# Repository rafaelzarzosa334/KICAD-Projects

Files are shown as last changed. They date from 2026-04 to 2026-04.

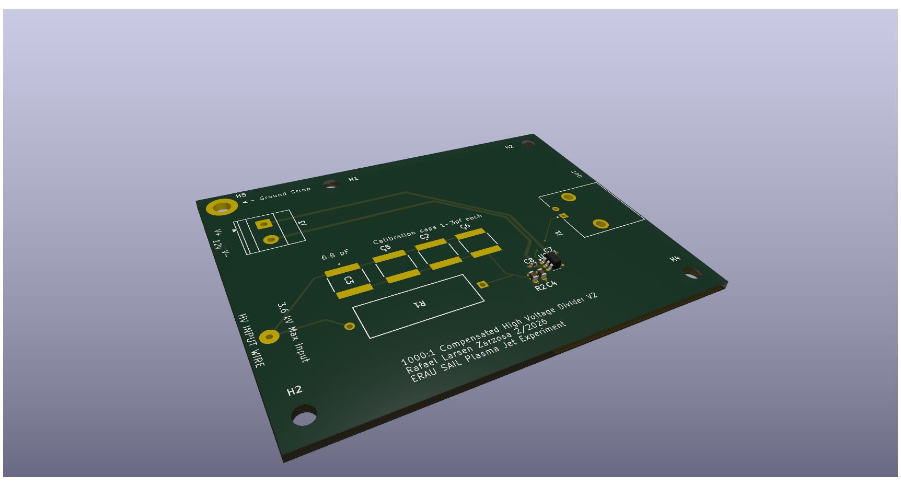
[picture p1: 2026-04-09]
HV_Divider v2 Render.png

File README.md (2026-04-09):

# High-Voltage Resistive-Capacitive Divider and Buffered Measurement System

## Overview
This project is a high-voltage resistive-capacitive (RC) divider designed to safely measure fast, high-voltage transients (~kV range) in plasma diagnostics applications. The system scales down high-voltage signals to a measurable range and incorporates an op-amp buffering stage to accurately interface with 50 Ω digitizers and oscilloscopes.

The design is intended for use in a plasma jet experimental setup, where rapid voltage changes and electromagnetic interference require careful signal conditioning and impedance management.

---

## Design Objectives
- Accurately scale high-voltage signals (~kV) to safe, measurable levels  
- Preserve fast transient response (µs timescale)  
- Minimize signal distortion and bandwidth limitations  
- Provide impedance matching to measurement equipment (50 Ω systems)  
- Isolate measurement electronics from high-voltage domains  
- Ensure reliable operation in a noisy plasma environment  

---

## System Description

### Resistive Divider Network
- High-voltage resistive divider (e.g., 1 MΩ / 1 kΩ configuration)  
- Reduces input voltage by a factor of ~1000:1  
- Designed to handle high voltage while maintaining measurement accuracy  

### Capacitive Compensation
- Parallel capacitors added across divider resistors  
- Compensates for frequency-dependent behavior of the divider  
- Tuned to maintain waveform fidelity for fast transient signals  

### Buffering Stage
- Unity-gain op-amp buffer (OPA140)  
- High input impedance minimizes loading on divider  
- Low output impedance enables accurate signal transmission to measurement equipment  

### Output Interface
- Designed to drive 50 Ω input impedance (oscilloscope/digitizer)  
- Prevents amplitude attenuation and signal distortion due to loading effects  

---

## PCB Design Considerations

### High-Voltage Safety
- Careful creepage and clearance spacing between HV and low-voltage nodes  
- Physical separation of HV input traces from signal conditioning circuitry  
- Layout designed to reduce risk of arcing and unintended coupling  

### Signal Integrity
- Short trace paths for sensitive analog signals  
- Minimization of parasitic capacitance and inductance  
- Controlled routing to preserve high-frequency signal components  

### Grounding Strategy
- Dedicated analog ground plane  
- Proper return paths to reduce noise and ground loops  
- Shielding considerations when used inside a metal enclosure (Faraday cage)  

---

## Applications
- Plasma diagnostics and high-voltage experiments  
- Pulsed power systems  
- High-voltage probe design  
- Fast transient voltage measurement systems  

---

## Key Components
- High-voltage resistors (divider network)  
- Compensation capacitors (C0G/NP0 preferred for stability)  
- Precision op-amps (OPA140)  
- SMA or coaxial output connectors for signal integrity  

---

## Files Included
- KiCad Project (KiCad 9.0)  
- KiCad schematic (KiCad 9.0)  
- PCB layout (KiCad Board 9.0)  
- Fabrication files (Gerbers)  
- Board rendering (.png)  

---

## Design Challenges & Solutions

### Challenge: Signal Attenuation Due to Measurement Equipment
Direct connection of the divider to a 50 Ω oscilloscope input caused significant amplitude reduction.

**Solution:**  
Implemented a unity-gain op-amp buffer to isolate the divider from the load and provide a low-output-impedance signal to the measurement system.

---

### Challenge: Preserving Fast Transient Response
High-voltage pulses in the plasma system occur on microsecond timescales, requiring adequate bandwidth.

**Solution:**  
Introduced capacitive compensation across the divider to match time constants and preserve waveform fidelity.

---

### Challenge: Noise and Interference from Plasma Environment
The measurement system operates in a high-EMI environment with strong electromagnetic disturbances.

**Solution:**  
Used a grounded enclosure (Faraday cage), careful PCB layout, and shielding practices to minimize noise coupling.

---

### Challenge: High-Voltage Isolation
Sensitive electronics must be protected from kV-level input signals.

**Solution:**  
Maintained strict separation between HV and low-voltage regions and designed the divider to safely drop voltage before buffering.

---

## Future Improvements
- Characterize bandwidth and frequency response experimentally  
- Improve impedance matching for long cable runs  
- Add transient protection (TVS diodes, filtering stages)  
- Perform calibration against a commercial high-voltage probe  

---

## Author
Rafael Larsen Zarzosa  
Mechanical Engineering Student – Embry-Riddle Aeronautical University  
Undergraduate Research Assistant – Space and Atmospheric Instrumentation Lab (SAIL)

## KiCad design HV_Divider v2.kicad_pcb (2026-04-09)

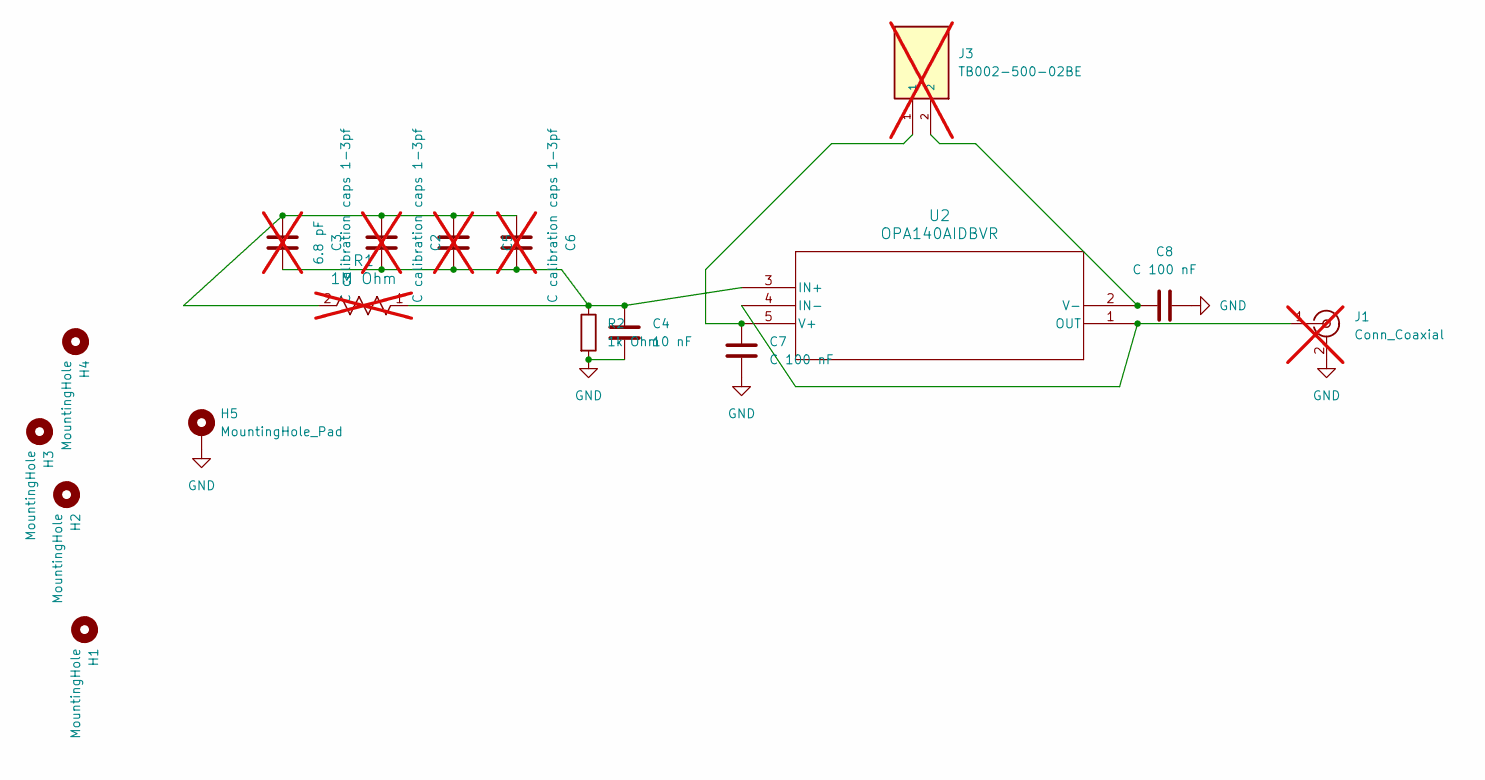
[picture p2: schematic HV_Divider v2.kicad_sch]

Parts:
C2, C5, C6: C calibration caps 1-3pf; CAP_2225_KNO-M; not fitted
C3: 6.8 pF; CAP_2225_KNO-M; not fitted
C4: 10 nF; C_0603_1608Metric
C7, C8: C 100 nF; C_0402_1005Metric
H1, H2, H3, H4: MountingHole; MountingHole_3.2mm_M3
H5: MountingHole_Pad; MountingHole_3.2mm_M3_DIN965_Pad
J1: Conn_Coaxial; LINX_CONBNC002; not fitted
J3: TB002-500-02BE; TerminalBlock_Phoenix_MKDS-1,5-2_1x02_P5.00mm_Horizontal; not fitted
R1: 1M Ohm; RES_VR68; not fitted
R2: 1k Ohm; C_0603_1608Metric
U2: OPA140AIDBVR; SOT-23-5

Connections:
GND: C4.2, C7.2, C8.2, H5.1, J1.2 (Ext), R2.2
unnamed 1: C2.1, C3.1, C5.1, C6.1, R1.2; also elsewhere on the board
unnamed: J1.1 (In), U2.1 (OUT), U2.4 (IN-)
unnamed: C2.2, C3.2, C4.1, C5.2, C6.2, R1.1, R2.1, U2.3 (IN+)
unnamed: C7.1, J3.1, U2.5 (V+)
unnamed: C8.1, J3.2, U2.2 (V-)

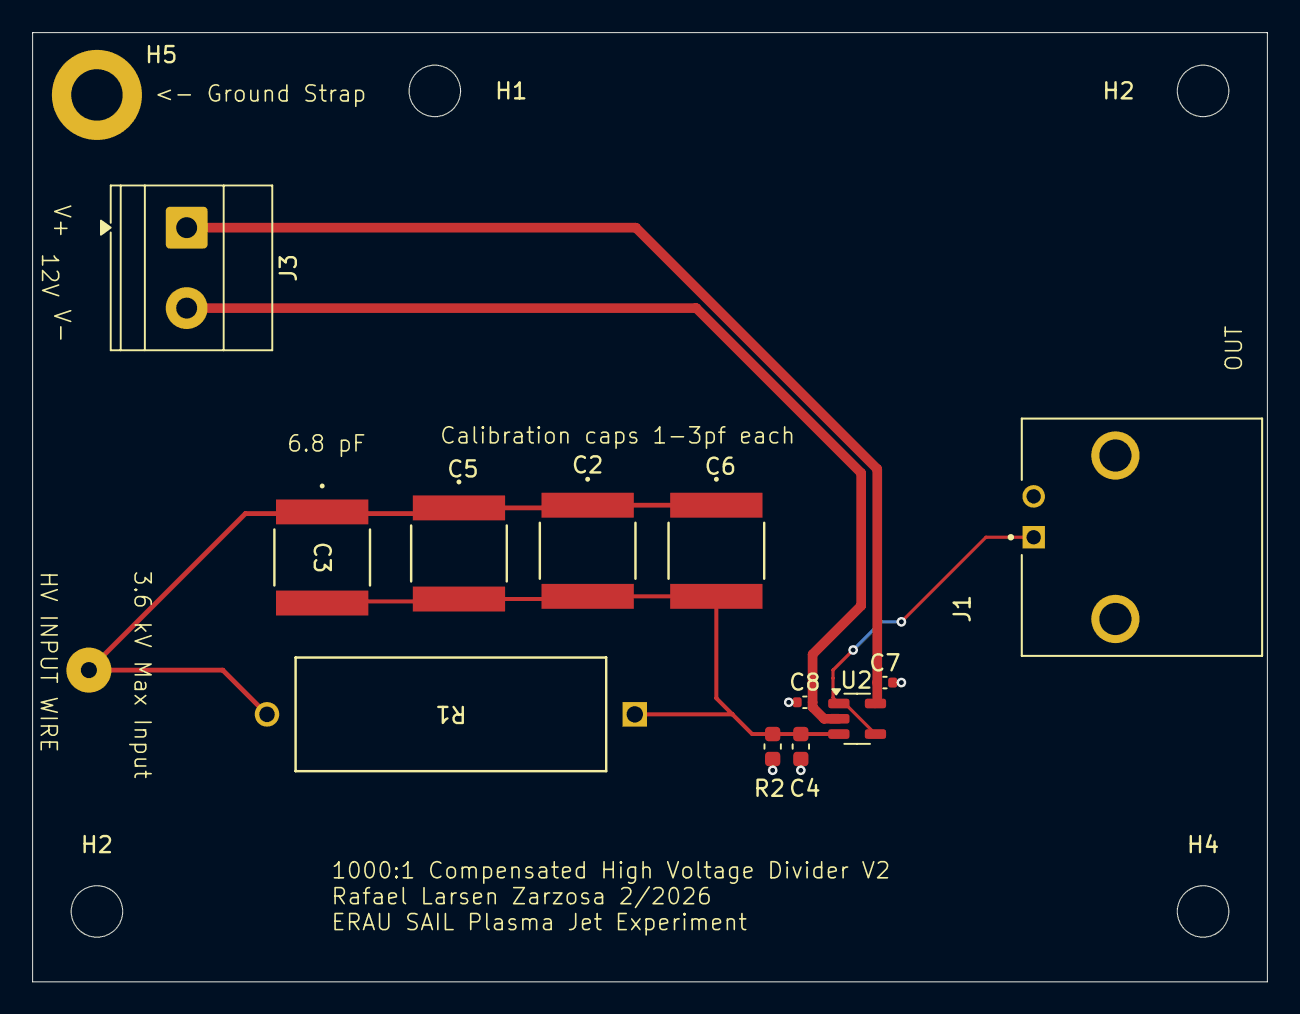
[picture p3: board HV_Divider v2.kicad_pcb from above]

Board: 2 copper layers, 76.8 x 59.0 mm, 18 parts (0 on the bottom side), 6 nets.

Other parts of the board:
H2#2: MountingHole; MountingHole_3.2mm_M3
HV INPUT WIRE: HV_Wire_pad_1mm; HV_WIRE_INPUT_THRUHOLE

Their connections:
unnamed 1: HV INPUT WIRE.1; also elsewhere on the board
